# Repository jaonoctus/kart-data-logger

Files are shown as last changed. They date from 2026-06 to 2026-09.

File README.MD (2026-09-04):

# ESP32 Kart Telemetry System

A telemetry and datalogging system for open-track go-karts, built around a single
steering-wheel-mounted ESP32 display board that handles everything: GPS
acquisition, lap timing, dashboard rendering and SD logging.

> **Note:** earlier revisions of this project split the work between a
> helmet-mounted logger node and the display, linked over ESP-NOW. That helmet
> node proved unreliable at the track and has been removed — the display is now
> the only node.

## System Architecture

Single target: the **Display Dashboard Node**.

* **Board:** JC3248W535N (ESP32-S3, AXS15231B QSPI panel)
* **Role:** GPS acquisition, lap detection, UI dashboard, and SD logging.
* **Features:**
  * GPS from ATGM336 (default) or u-blox M9, wired directly to the board.
  * Live speed, G-force, satellite count and display battery state.
  * Finish-line based lap detection with best/previous lap deltas.
  * Telemetry logged to SD card per recording session.
  * Optional MPU6050 IMU for speed filtering and steering angle.

### Build targets in `platformio.ini`

Both targets build the same application (`src/main_display.cpp`) and differ only
in the panel driver backend:

* `env:display_gfx` — Arduino_GFX backend (`lib/DisplayGFX`). **Default.**
* `env:display` — esp_lcd backend (`lib/DisplayBSP`). Fallback.

The Arduino_GFX backend is the default because it resolves a QSPI panel wedge
seen with the esp_lcd path.

## Key Technical Features

* **Modular GPS provider** abstraction in `GpsManager`.
* **Finish-line lap detection** in `LapManager`, driven by GPS position.
* **`fix_stride.py` prebuild patch** for SquareLine Studio LVGL 9 image exports.
* **Display-wedge watchdog** — a 5s task watchdog on `loopTask` turns a panel
  wedge into a fast auto-reset instead of a permanent freeze.
* **Charge mode** to keep the board from eating the charger's current budget.
* **Optional IMU support** to improve speed filtering and live telemetry.

## Charge mode

The charger's current is shared between the board and the cell, so a running
dashboard slows charging considerably. Charge mode parks the device:

* Stops the recording session and closes the GPS UART.
* Drops the CPU to 80 MHz (the floor for stable USB-CDC — don't go lower).
* Swaps to a minimal charge screen and blanks the backlight after 15s.

It is **only ever entered manually**, from the `CHARGE MODE` button on the
config screen. Nothing enters it automatically, so bench testing and debugging
are unaffected.

While parked: tap anywhere to wake the backlight and read the battery for
another 15s; press `RESUME` to leave. Resuming re-probes the GPS, which takes a
couple of seconds.

> **Whether the GPS actually sleeps depends on which one is fitted.** Charge mode
> calls `gps.standby()` and leaves the UART open so `wake()` can talk to it.
> On the **ATGM336** that is a quiesce, not a sleep: the RF front end has no
> software power-down at all, so it keeps drawing ~25-40 mA and standby only cuts
> it to GPS-only at 1Hz with NMEA muted. On the **u-blox M9** it is a real
> power-down — `UBX-RXM-PMREQ` software backup, woken by traffic on the module's
> RX pin. Coming back may cost a cold start if the module's V_BCKP does not hold
> the BBR, but the configuration itself is in flash and survives either way.

> **The percentage reads high while charging.** With no power-path charger the
> sense divider sits on the charger rail, so it measures the cell terminal
> voltage *under charge*, which is well above its resting value — expect a
> jump downward when you unplug. It's shown as `~94%` to mark it approximate;
> the voltage below it is the number to trust.

The charge screen and the config-screen button are both built at runtime in
`lib/UiHelper/uiHelper.cpp` rather than exported from SquareLine, so
re-exporting `lib/ui/` will not wipe them.

## Hardware Requirements

* JC3248W535N display board
* GPS module wired to `RX=6` / `TX=7` — ATGM336, or a u-blox M9 such as the Matek
  M9N-5883. The ATGM336 runs on 3V3; the M9N-5883 wants 4~5.5V, so its VCC belongs
  on the IP5306 5V rail, not the board's 3V3.
* Optional MPU6050 IMU
* microSD card formatted FAT32

## Software Dependencies

Built with PlatformIO.

* `lvgl/lvgl` (v9.x)
* `moononournation/GFX Library for Arduino` (`display_gfx` only)
* `mikalhart/TinyGPSPlus`
* `ElectronicCats/MPU6050`

## GPS Providers

`GpsManager` supports two providers. Nothing older than these is supported — the
NEO-6M-era 9600-baud fallback is gone.

* **ATGM336 provider** (current default)
  * Enabled with `-D GPS_PROVIDER_ATGM336`.
  * 10Hz.
  * Configured over CASIC text commands (`$PCAS`), which are never acked, so the
    module cannot report whether a setting took. It also cannot be put to sleep:
    `$PCAS12` standby is a 5L-only feature and this is a 5N.
* **u-blox M9 provider** — targets the M9 generation (NEO-M9N), e.g. the Matek
  M9N-5883.
  * Leave `-D GPS_PROVIDER_ATGM336` out of the build flags.
  * 25Hz.
  * Probes 115200 then 38400 (the M9 default), and moves the port to 115200.
  * Sleeps for real in charge mode — `UBX-RXM-PMREQ` software backup, armed to
    wake on UART RX traffic.
  * Configured over binary UBX, which *is* acked, and the provider reads the
    dynamic model / rate / power mode back at boot and logs `BEFORE:` and
    `AFTER:` lines. Legacy `UBX-CFG-*` messages are deprecated on generation 9
    but still supported; they are removed on generation 10, so a future module
    means porting `configureUblox()` to `UBX-CFG-VALSET`.
  * **Speaks `UBX-NAV-PVT`, not NMEA.** All NMEA output is disabled. One 92-byte
    frame per epoch carries position at 1e-7° (~1.1cm), Doppler ground speed,
    UTC, `numSV`, `fixType`, `pDOP`, `hAcc` and `sAcc` — less traffic than
    GGA+RMC and strictly more information, as one coherent snapshot instead of a
    position from one sentence stitched to a speed from another. It also makes the
    four-constellation problem vanish: per-system duplication of GSA/GSV was an
    NMEA artefact, and UBX has no talker IDs to multiply.
  * `hasFix()` therefore uses the receiver's own verdict — `gnssFixOK`,
    `fixType == 3`, and `hAcc` within bounds — rather than the `sats >= 4 &&
    HDOP <= 3` heuristic the NMEA path had to guess with.
  * **TinyGPSPlus is unused on this path.** It stays in `lib_deps` for the
    ATGM336, and static-archive linking drops it (and the unreferenced provider)
    from the image. It is still compiled every build, so a break in either
    provider still fails the build.

The flag lives in `[display_common] -> build_flags_base`, so it applies to both
build targets at once.

### Fix rate

ATGM336 runs at **10Hz**, u-blox M9 at **25Hz** — the receiver's ceiling with all
four constellations. GGA+RMC at 25Hz is ~36kbaud of the 115200 the port is set to,
so the link has room to spare. 40ms epochs also land on exact centisecond values
(`.00`/`.04`/`.08`…), which matters because NMEA timestamps are centiseconds and
anything finer would round.

The rate buys **log resolution**, which is the point — at 100 km/h, 25Hz puts a
sample every 1.1m instead of every 2.8m. It buys much less for lap times, because
`LapManager` intersects the finish gate with the segment between consecutive fixes
and interpolates the crossing millisecond along it, so the reported time never
quantised to the fix interval in the first place.

To sustain 25Hz, `LogManager` holds the log file open for the whole session and
`flush()`es once a second, rather than reopening and closing it per row (25 FAT
directory updates a second is where a slow card starts stalling). The trade is
durability: an abrupt power-off now costs up to a second of the lap instead of a
single sample. The telemetry queue is 40 frames for the same reason — ~1.6s of
headroom at 25Hz, so a card stall doesn't drop rows.

### GPS wiring

The GPS UART pins are set by `GPS_STANDALONE_RX` / `GPS_STANDALONE_TX` in
`[display_common]`, currently `6` and `7`.

Watch for collisions when changing these: `GPIO5` carries the battery sense
divider (`DISPLAY_BATT_ADC` in `src/main_display.cpp`), and `GPIO18`/`GPIO17`
are the IMU's I2C pins when `ENABLE_IMU` is set.

## Filesystem & Storage

The display reads and writes to a **FAT32 microSD** card. No files need to be
pre-populated — the display creates what it needs on first boot — but the files
below may be edited on a computer for configuration.

#### `/config.ini` (auto-created)

Stores display preferences. Created with defaults on first boot if absent.

```ini
# Kart Data Logger Configuration
theme=dark          # dark | light
selected_track=0    # index into tracks.ini
```

#### `/health.csv` (auto-created, only when something goes wrong)

Appended across every session, one row per second in which the telemetry queue
had no room for a frame:

```
epoch,log,dropped_total,dropped_delta
```

**An empty or absent file is the good news** — it means no row was ever lost. Any
row in it means the card could not keep up with the fix rate and the matching
`log_N.csv` is missing samples, so the file is worth checking after a race rather
than watching the serial log, which is unreachable with the dash on a wheel.

`epoch` comes from the GPS-synced system clock, so it lines up with the `epoch`
column in the telemetry file; before the first fix it degrades to uptime.

#### `/tracks.ini` (optional, user-created)

Defines named tracks with GPS finish-line coordinates. The display reads this at
boot and populates the track selector in the UI. If absent, no tracks are
preloaded.

```ini
# Kart track configurations
count=2

0_name=Kartódromo Granja Viana
0_left_lat=-23.60488969
0_left_lon=-46.83622658
0_right_lat=-23.60493793
0_right_lon=-46.83641597

1_name=My Track
1_left_lat=0.00000000
1_left_lon=0.00000000
1_right_lat=0.00000000
1_right_lon=0.00000000
```

#### `/log_N.csv` (auto-created per session)

Telemetry session logs. A new numbered file is created each time a recording
session starts.

```
epoch,speed,totalGForce,gForceX,gForceY,steering_angle,sats,lat,lng,fix,pdop,hacc,sacc
```

The last four are the receiver's report on its own fix, and are **zero on the
ATGM336** — NMEA carries no equivalent, so zero means "not reported", not "perfect".

| column | meaning |
| --- | --- |
| `fix`  | `0` no fix, `2` 2D, `3` 3D, `5` time only. Never `1`/`4` (dead reckoning) — that is NEO-M9V silicon, not M9N. |
| `pdop` | position dilution of precision |
| `hacc` | horizontal accuracy estimate, metres, ~1σ |
| `sacc` | speed accuracy estimate, m/s |

`hacc` is the useful one for analysis: it does not make a position better, it tells
you which samples to distrust. Around 0.7-1.5m under open sky, climbing near
buildings and in the first seconds after a cold start. A lap time interpolated
between two 12m samples is not a lap time to trust to hundredths.

These columns are **appended**, never inserted, so everything in `tools/` keeps
working — those read by column name or by a fixed `sscanf` prefix. A CSV derived
from GoPro footage simply lacks them.

Note `lat`/`lng` are written at 7 decimal places (~1.1cm) rather than 6 (~11cm),
which is what `UBX-NAV-PVT` actually resolves.

## Setup & Installation

1. Clone this repository.
2. Open it in VSCode with PlatformIO.
3. Edit the UI using the SquareLine Studio project files in `UIDesign/`.
4. Export the UI to `/lib/ui/` and let `fix_stride.py` patch LVGL image metadata during build.
5. Flash the firmware: `tools/flash.sh` (see below).
6. Insert a FAT32 microSD card into the display. A default `config.ini` is created on first boot.

### Flashing

`upload_port` in `platformio.ini` is pinned to `/dev/cu.usbmodem1101`, which is one
machine's enumeration — the same board comes up under a different name elsewhere and
`pio run -t upload` then fails on a port that isn't there. `tools/flash.sh` finds the
board by USB `VID:PID` instead and passes it with `--upload-port`, which overrides the
pinned value:

```bash
tools/flash.sh              # default env, confirm, then upload
tools/flash.sh -m           # ...and open the serial monitor afterwards
tools/flash.sh -e display   # the esp_lcd fallback env
tools/flash.sh -p /dev/cu.usbmodem101   # skip discovery
tools/flash.sh -y           # no confirmation prompt (also FLASH_YES=1)
tools/flash.sh -- -v        # anything after -- goes to `pio run`
```

Before uploading it prints the port, env and `FW_VERSION`, and warns if the tree is
dirty — `FW_VERSION` is `git describe --tags --always --dirty` and shows on the setup
screen, so it is easy to flash uncommitted edits by accident. If more than one board is
attached it lists the candidates and asks for `-p`.

`pio run -e display_gfx -t upload` still works if the pinned port happens to be right.

## Dormant libraries

These libraries are no longer part of the build — nothing includes them — but
they are kept in `lib/` because they may be useful again:

* `EspNowManager` + `Shared/EspNowProtocol.h` message types — the board-to-board radio link.
* `ErrorLogManager` — LittleFS error capture and transfer.
* `AudioManager`, `VoiceParser` — I2S playback and spoken number/lap announcements.
* `PowerManager` — button-driven hibernate and power gating.
* `FakeGps` — CSV replay for development without GPS hardware.

`Shared/EspNowProtocol.h` is still compiled: `TelemetryMsg` is the record the
display passes between the UI, the lap manager and the SD log task.

## Design files

Design files are included under the `hardware/` folder.

### 3D Models

I've used Fusion to design 3D models for the custom enclosures and mounts. These
are located in `hardware/3d-models/` and exported as `.f3d` and `.3mf` files.
You can open and modify these in Fusion or any compatible 3D modeling software.

## Visual Reference

The repository includes module photos in the `images/` folder.

Wheel module assembled

## Notes

* The display firmware owns the whole pipeline: GPS, lap timing, UI and SD logging.
* Lap detection only runs while a recording session is active.

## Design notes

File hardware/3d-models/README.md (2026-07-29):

# 3D Models

This folder contains the Fusion 360 source models and assembly exports used to validate the kart display enclosure and its subcomponents.

## Included files

* `Display.f3d` — main display enclosure model.
* `Display Assembly.3mf` — assembly export showing how the display, rear cover, battery support, and wheel holder fit together.
* `Battery.f3d` — battery pack model and holder details.
* `4056 Battery Charger.f3d` — USB-C charging board model and placement.
* `GPS.f3d` — GPS enclosure model.
* `MP6050.f3d` — IMU module model.

## Design intent

The primary part is `Display.f3d`. The other models were created to build the assembly and verify that all pieces fit correctly.

## Mounting and fastening

* The display board is held in place by small pegs that fit into matching bosses in the enclosure.
* The back cover is pressed onto the display body by rear cover pegs and then bolted in place.
* The back cover uses eight `M3X3X5` heat inserts and eight `M3x6` bolts.
* The GPS enclosure uses four `M2.5x6mm` bolts and four `M2.5x4x4mm` heat inserts.
* The GPS holder fits the ATGM336 module and a `25x25mm` antenna.

## Battery and charging

* The rear cover supports a `LGBH4ZB4857` 2000mAh battery.
* The battery is sourced from a Dell Latitude 5490 battery pack, which contains three of these cells.
* A `4056` 1A USB-C charging board is integrated into the back cover space.

## Wheel holder and battery cover

* The battery cover / wheel holder assembly is not permanently fixed to the back cover.
* It is held in place by velcro loops that attach from the front of the display case, securing the assembly without rigid fasteners.
* The wheel holder is fixed to the rear plate using four `M3X3X5` heat inserts and four `M3x6` bolts.
* This wheel holder section can be modified for different kart wheel sizes, or multiple sizes can be printed and swapped without redesigning the entire case.

## IMU placement

* The IMU is mounted to the front of the battery back plate using double-sided tape.

## Notes

* Use the Fusion 360 `.f3d` files for source edits and design updates.
* The `.3mf` assembly file is useful for fit verification and export to compatible printing workflows.
* Confirm fastener lengths and insert positions before printing if you modify the enclosure geometry.

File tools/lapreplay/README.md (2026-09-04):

# Lap replay harness

Offline test rig for finish-line detection. Turns a GoPro's telemetry into the
logger's own CSV format and replays it through the **real** `lib/LapManager`
compiled for the host — so lap detection can be validated without going to the
track.

Nothing here is part of the firmware build. `tools/` is outside `build_src_filter`
and `lib/`, so PlatformIO never sees it.

`make` also builds **`navpvt`**, an offset-level check on the real
`UbloxGpsProvider::update()` — it feeds synthetic `UBX-NAV-PVT` frames through a
byte-queue serial stub and asserts what the provider decodes. Run it after touching
that provider: it decodes by explicit byte offset, and a wrong offset does not crash,
it produces plausible telemetry that is silently wrong. It covers the field offsets,
the `hasFix()` gates (2D rejected, `hAcc` bound), checksum rejection, mm/s→km/h
scaling, and a frame split at every byte boundary — that last one being the real 25Hz
failure mode, where a message straddles two `update()` calls because the UART buffer
drained mid-frame.

## Why a GoPro

GoPro MP4s carry a GPMF metadata track alongside the video. On a HERO8 that is
GPS at ~18 Hz and accelerometer/gyro at ~200 Hz — denser than the ATGM336's
10 Hz, already timestamped in UTC, and free if you were filming anyway.

## Usage

```sh
# 1. extract telemetry -> CSV (no ffmpeg/exiftool needed; parses the MP4 directly)
python3 gpmf_to_csv.py ../../video/GH011973.MP4 GH011973.csv

# 2. build the harness
make

# 3. replay against a finish line: <csv> <leftLat> <leftLng> <rightLat> <rightLng>
./replay GH011973.csv -23.60488969 -46.83622658 -23.60493793 -46.83641597
```

`make VERBOSE=1` surfaces `LapManager`'s own `log_d()` gate diagnostics
("Approaching Gate", "Gate Missed!", "VALID CROSSING") which are compiled out by
default.

### Testing lap *timing*

A single crossing only starts the clock — it produces no lap time. If the clip is
a near-closed loop, stitch it into synthetic laps:

```sh
python3 gpmf_to_csv.py ../../video/GH011973.MP4 looped.csv --repeat 4
./replay looped.csv -23.60488969 -46.83622658 -23.60493793 -46.83641597
```

Each reported lap should equal the printed span exactly; any drift is a bug in
the crossing interpolation.

## Column mapping

Output matches `LogManager::task`'s `/log_N.csv` exactly:

```
epoch,speed,totalGForce,gForceX,gForceY,steering_angle,sats,lat,lng
```

| column | source | notes |
|---|---|---|
| `epoch` | `GPSU` | absolute UTC, 1 Hz; the 18 Hz `GPS5` samples are interpolated between stamps |
| `speed` | `GPS5` 2D speed | m/s → km/h |
| `totalGForce` | `ACCL` magnitude | orientation-independent, always correct |
| `gForceX/Y` | `ACCL` axes | **see caveat below** |
| `steering_angle` | — | always `0.0`; a camera cannot know this |
| `sats` | `GPSF` | GPMF has no satellite count, only fix type and DOP. Emitted as `12` on a 3D fix, else `0`, because `LogManager` and `LapManager` treat `sats == 0` as unusable |
| `lat`/`lng` | `GPS5` | 6 dp, ~0.11 m resolution |

**Axis caveat:** GPMF's accelerometer axis order depends on camera mount
orientation (see the `ORIN`/`ORIO` tags). The X/Y assignment is a starting guess —
verify against a known corner before trusting `gForceX`/`gForceY`. Raw accel also
peaks around 6 g from chassis vibration, so samples are averaged into each GPS
interval to damp it.

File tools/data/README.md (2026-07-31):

# Recorded GPS tracks

Raw GPS as it came off the GoPro's GPMF track, one file per chapter of a single
12-lap session (Kartódromo Granja Viana, 2026-07-23). Committed because the
source footage is ~1.2 GB and lives outside the repo: with these, lap detection
can be exercised on real track data without it.

| file | samples | span | notes |
|---|---|---|---|
| `gps_raw_GH011974.csv` | 9,548 | 532.8 s | starts before the race; 2 corrupt near-(0,0) samples left in |
| `gps_raw_GH021974.csv` | 7,508 | 423.2 s | continues the same recording past the 4 GB split |

Both are ~18 Hz, 3D fix throughout, DOP 1.1–1.9. Columns and their exact
provenance are documented at the top of `../lapreplay/gpmf_gps_raw.py`; nothing
is filtered or converted, including the corrupt samples.

## Replaying them

`gps_raw_to_log.py` merges the chapters back into one session in the logger's
own CSV format, which `replay` feeds through the firmware's real `LapManager`:

```sh
cd ../lapreplay && make
python3 gps_raw_to_log.py --out /tmp/session.csv ../data/gps_raw_GH0*1974.csv
./replay /tmp/session.csv -23.605392 -46.836045 -23.605442 -46.836251
```

That yields 12 crossings, best lap 1:02.628 — identical to what the full
video-derived pipeline (`tools/overlay/prepare.py`) produces, so this is a
faithful stand-in for it and a usable regression fixture.

## What is *not* here

No video timeline. GPMF telemetry does not sit at a fixed offset from the
picture — the overlay needed ~1.2 s of correction on chapter 1 and closer to
2 s on chapter 2 — so the two cannot be related without re-measuring per clip.
The GPS timeline against itself is sound, which is the part that matters for
lap logic.

No accelerometer. The g-force channels need axis calibration against gyro and
speed, which `gpmf_to_csv.py` does from the video.

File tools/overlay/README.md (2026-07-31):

# Telemetry overlay

Renders a dashboard-style overlay onto GoPro race footage: track map, g-force
wheel, speed, race/lap time and lap number. Telemetry comes from the videos' own
GPMF track, so nothing has to be recorded on the device.

Lap numbers come from the firmware's **real** `LapManager`, via
`tools/lapreplay/replay --csv`. The overlay and the kart dashboard therefore
agree by construction rather than by a reimplementation that can drift.

## Requirements

* `ffmpeg` on PATH — `brew install ffmpeg`
* Pillow — already installed in `.venv/` here (`python3 -m venv .venv && .venv/bin/pip install Pillow`)
* `tools/lapreplay/replay` built — `cd ../lapreplay && make`

## Usage

```sh
# 1. order the clips, merge telemetry, trim to race start, detect laps
python3 prepare.py \
    --videos ../../video/*.MP4 \
    --race-start GH011974.MP4:186 \
    --finish-line -23.60488969 -46.83622658 -23.60493793 -46.83641597 \
    --outdir build

# 2. render (start/duration are seconds after the race start)
.venv/bin/python render.py --config build/session.json \
    --start 210 --duration 3 -o test.mp4
```

`--frames-only DIR` writes PNG frames instead of encoding, which needs no
ffmpeg and is the quick way to check layout changes.

Output defaults to 1080p. The source is 4K, so ffmpeg downscales it — 4K output
is enormous and very slow to encode for no real benefit when watching.

## Telemetry lag

GPMF telemetry runs behind the picture: the overlay reacts about a second after
the corner is already on screen. `--lag` advances the telemetry against the
video and defaults to **1.2 s**, chosen by rendering the same braking-and-corner
section at 1.2 / 1.4 / 1.5 / 2.0 / 2.5 and watching which one lands.

GPS and accelerometer lag together — cross-correlating `ACCL` against the
GPS-derived lateral acceleration puts them within 0.17 s of each other — so
`--lag` moves both. `--lag-g` can shift only the g-wheel if you ever want them
apart; it defaults to whatever `--lag` is.

```sh
.venv/bin/python render.py --config build/session.json \
    --start 210 --duration 12 --lag 1.4 -o lagtest_1.4.mp4
```

## Clip ordering

`prepare.py` orders clips by the UTC in their GPMF track, **not** by filename.
This matters: GoPro splits a single recording at the 4 GB FAT32 limit into
`GH01xxxx`, `GH02xxxx`, … so chapter 2 of one recording sorts before chapter 1
of the next, and unrelated recordings can interleave.

Clips separated by more than `--max-gap` seconds (default 5) from the previous
one are treated as a different session and dropped, with a note. For this
footage that correctly kept `GH011974` + `GH021974` (consecutive chapters,
seamless) and dropped `GH011975`/`GH011976`, which were recorded 14 hours later.

## Accelerometer axes

GPMF's accelerometer axis order depends on how the camera was mounted, so
`gpmf_to_csv.calibrate_axes()` derives it from the data:

* **vertical** — the axis carrying gravity (largest absolute mean)
* **lateral** — the horizontal axis correlating with `v × yaw_rate`, because
  cornering acceleration is exactly that
* **longitudinal** — whichever horizontal axis remains

Yaw is rotation about the vertical axis, so the gyro axis used is the same index
as the gravity axis; if those disagree the calibration is suspect. On this
footage both chapters independently resolved to `vertical=0, lateral=1,
longitudinal=2` with r ≈ +0.55.

Each axis's mean is subtracted, which removes gravity and any camera tilt
leaking into the horizontal axes. `totalGForce` is therefore the **horizontal**
magnitude — including gravity would make it read ~1 g at a standstill and would
not match the position of the dot on the wheel.

Residual peaks around 3–4 g are kart chassis vibration, not real cornering load;
the accelerometer samples inside each GPS interval are averaged to damp it.

## Layout

| element | position | source |
|---|---|---|
| lap number, current lap, last, best | top left | `laps.csv` from `LapManager` |
| race clock | top right | elapsed since race start |
| speed | bottom centre | `GPS5` 2D speed |
| g-force wheel, 1 g / 2 g rings | bottom right | calibrated `ACCL` |
| track map, finish line, position | bottom left | `GPS5` lat/lng |

Colours are the dashboard's `THEME_NIGHT` palette from `lib/UiHelper/uiHelper.h`.

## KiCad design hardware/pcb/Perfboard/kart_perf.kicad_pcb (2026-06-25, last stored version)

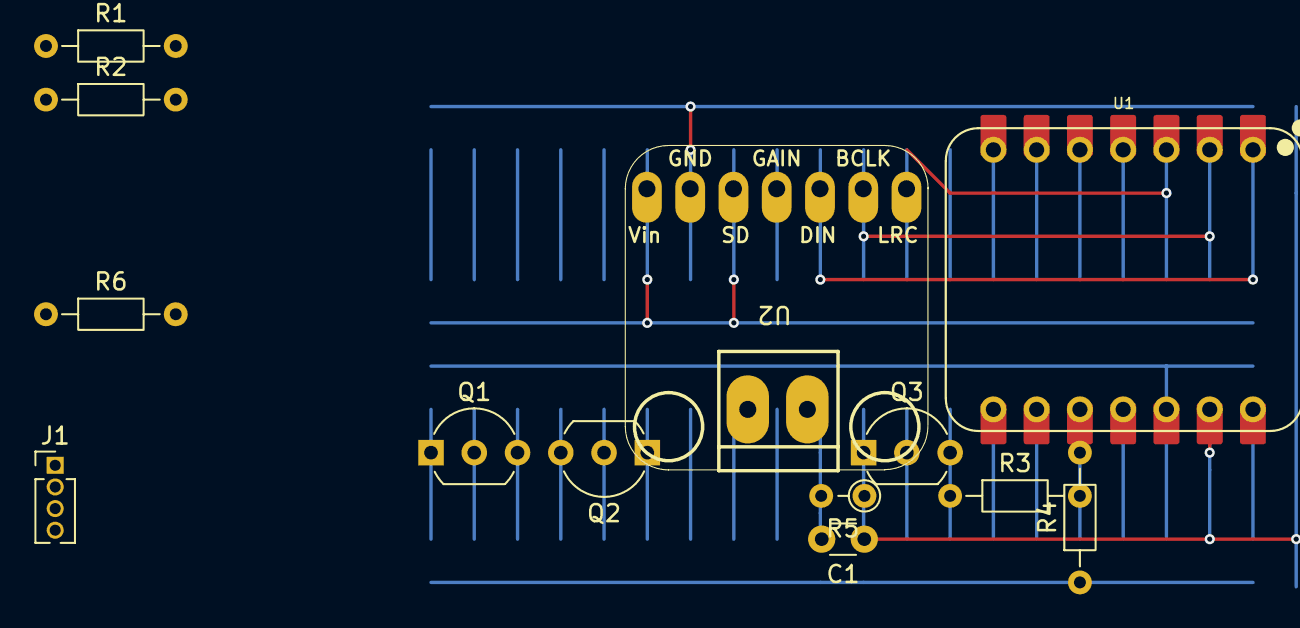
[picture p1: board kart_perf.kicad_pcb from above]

Board: 2 copper layers, 13 parts (0 on the bottom side), 16 nets.

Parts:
C1: 0.1uf; C_Disc_D3.0mm_W1.6mm_P2.50mm
J1: Conn_01x04_Pin; PinHeader_1x04_P1.27mm_Vertical
Q1: BC327; TO-92_Inline_Wide
Q2, Q3: 2N3904; TO-92_Inline_Wide
R1, R3, R6: 10k; R_Axial_DIN0204_L3.6mm_D1.6mm_P7.62mm_Horizontal
R2: 470; R_Axial_DIN0204_L3.6mm_D1.6mm_P7.62mm_Horizontal
R4: 1M; R_Axial_DIN0204_L3.6mm_D1.6mm_P7.62mm_Horizontal
R5: 1M; R_Axial_DIN0204_L3.6mm_D1.6mm_P2.54mm_Vertical
U1: XIAO-ESP32-S3-SMD; XIAO-ESP32-S3-DIP
U2: adafruit-MAX98357

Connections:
+3.3V: Q1.3 (E), R1.2, U1.12 (3V3)
/BATT_EN: R6.2, U1.11 (GPIO9_A10_D10_MOSI)
/PERIF_EN: R3.1, U1.4 (GPIO4_A3_D3)
/SENSE: C1.2, R4.2, R5.2, U1.10 (GPIO8_A9_D9_MISO)
/V_PERIF: J1.3, Q1.1 (C), U2.1 (Vin), U2.3 (~SD_MODE)
GND: J1.4, Q2.1 (E), Q3.1 (E), U1.13 (GND), U2.2 (GND)
unnamed: J1.1, U1.7 (GPIO43_D6_TX)
unnamed: J1.2, U1.8 (GPIO44_D7_RX)
unnamed: Q1.2 (B), R1.1, R2.1
unnamed: Q2.2 (B), R3.2
unnamed: Q2.3 (C), R2.2
unnamed: Q3.2 (B), R6.1
unnamed: C1.1, Q3.3 (C), R5.1
unnamed: U1.1 (GPIO1_A0_D0), U2.5 (DIN)
unnamed: U1.2 (GPIO2_A1_D1), U2.6 (BCLK)
unnamed: U1.3 (GPIO3_A2_D2), U2.7 (LRC)

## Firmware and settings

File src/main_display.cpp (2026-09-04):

#include <Arduino.h>
#include "esp_task_wdt.h"   // display-wedge safety net (used throughout)
#include "esp_system.h"     // esp_reset_reason

// QSPI flush telemetry from lib/DisplayBSP/lv_port.c (C linkage). Reported once a
// second below via log_w so it surfaces at CORE_DEBUG_LEVEL=WARN.
extern "C" {
    extern volatile uint32_t lvgl_port_frame_drops;
    extern volatile uint32_t lvgl_port_max_stall_us;
}

// Library includes from our new /lib folder
#include "LogManager.h"
#include "EspNowProtocol.h"
#include "uiHelper.h"
#include "BatteryManager.h"
#include "ConfigManager.h"
#include "LapManager.h"
#include "GpsManager.h"

#if defined(ENABLE_GOPRO)
#include "GoProManager.h"
#endif

#if defined(ENABLE_WEB_PORTAL)
#include "WebPortal.h"
#endif

#include "SessionBrowser.h"
#include "LogBuffer.h"
#include "LogScreen.h"

// Opens the on-device session review screens. Called from the config screen,
// already in LVGL context — the browser loads a placeholder and repaints before
// the (slow) SD read, so the press feels immediate.
extern "C" void ui_helper_open_sessions(void) {
    sessionBrowser.openList();
}

// Opens the log screen. Reached from the config screen and from the dashboard
// alert banner. Renders out of LogBuffer's RAM ring, so unlike the session
// browser there is no slow read to defer — it can run in LVGL context.
extern "C" void ui_helper_open_logs(void) {
    logScreen.open();
}

#if defined(ENABLE_IMU)
#include "ImuManager.h"
#include "CalibrationManager.h"

#define I2C_SDA 18
#define I2C_SCL 17
#endif

const uint8_t timeBetweenImuReads = 10; // ms between IMU reads (100 Hz)

// --- GLOBAL STATE ---
LogManager logManager;
UiHelper   uiHelper;
LapManager lapManager;

GpsManager gps(GPS_STANDALONE_RX, GPS_STANDALONE_TX);

#if defined(ENABLE_GOPRO)
GoProManager goPro;
#define GOPRO_UI_INTERVAL_MS 500
static uint32_t lastGoProUiMs = 0;
#endif

#if defined(ENABLE_WEB_PORTAL)
WebPortal webPortal;
#define WEB_PORTAL_UI_INTERVAL_MS 1000
static uint32_t lastWebUiMs = 0;

// Called from the config-screen button (LVGL context). start() brings up the
// SoftAP and HTTP server, which takes a moment — acceptable here because the
// user just pressed a button and the portal task does the serving.
extern "C" void ui_helper_toggle_wifi(void) {
    if (webPortal.isRunning()) {
        webPortal.stop();
#if defined(ENABLE_GOPRO)
        goPro.resumeRadio();
#endif
        uiHelper.setWifi(false, 0, nullptr);
        return;
    }

    // WiFi needs ~50 kB of internal DRAM and cannot use PSRAM; NimBLE is
    // holding a comparable amount, so the BLE stack stands down first.
    // Otherwise esp_wifi_init fails with ESP_ERR_NO_MEM.
#if defined(ENABLE_GOPRO)
    goPro.suspendRadio();
#endif
    bool up = webPortal.start();
    if (!up) {
#if defined(ENABLE_GOPRO)
        goPro.resumeRadio();      // give it back, we did not need it after all
#endif
        uiHelper.setWifiError();  // say so on the button rather than sit silent
        return;
    }
    String wip = webPortal.ip();
    uiHelper.setWifi(true, webPortal.clients(), wip.c_str());
}
#else
extern "C" void ui_helper_toggle_wifi(void) {}
#endif

// Latest assembled telemetry frame. Written by loop() from the local GPS (plus
// IMU when enabled), consumed by syncUI() for the dashboard and the SD log.
static TelemetryMsg telemetry = {};
static bool newTelemetryAvailable = false;

#if defined(ENABLE_IMU)
ImuManager imu;
CalibrationManager calibManager(imu);
ImuData latestImuData = {0};
bool imuReady = false;
uint32_t lastImuReadMs = 0;
#endif

// Display battery: BAT+ → 68k (683) → IO5 → 100k (01D) → GND (always-on divider)
// Theoretical ratio is 1.68; the ADC reads low (~40k source impedance starves its
// sample-and-hold), so it is fitted to a multimeter instead. To re-fit: scale by
// meter/reported, on battery only — with USB in the node is the charger rail.
// ponytail: gain-only fit, exact at ~4.0V. If it reads high near 3.5V, take a point
// down there and go two-point (gain + offset).
#define DISPLAY_BATT_ADC 5
#define DISPLAY_BATT_READ_INTERVAL_MS 5000
BatteryManager displayBattery(DISPLAY_BATT_ADC, 0xFF, 1.7269f);
static uint32_t lastDisplayBattReadMs = 0;

// Smoothing & Metrics
float displaySpeed = 0;
float targetSpeed = 0;
const float lerpFactor = 0.20f;
static uint32_t lastHealthReportMs = 0;

// Lap state — updated inside syncUI()
static uint8_t s_lapCount = 0;

// Push a track's split gates into LapManager. Must follow setFinishLine(),
// which clears them — the splits belong to a track, so a new finish line
// invalidates them.
static void applySectorGates(const TrackConfig *t) {
    if (!t) return;
    FinishLine s1 = { t->s1.left_lat, t->s1.left_lon, t->s1.right_lat, t->s1.right_lon };
    FinishLine s2 = { t->s2.left_lat, t->s2.left_lon, t->s2.right_lat, t->s2.right_lon };
    lapManager.setSectorGates(t->s1.usable() ? &s1 : nullptr,
                              t->s2.usable() ? &s2 : nullptr);
}

// ============================================================================
// CHARGE MODE
// Entered only from the CHARGE MODE button on the config screen — never
// automatically — so debugging and bench testing are unaffected.
// Parks the device so the charger's current budget goes to the cell instead of
// the load: GPS off, session stopped, CPU down, backlight on a timeout.
// ============================================================================
#define CHARGE_CPU_MHZ              80     // USB-CDC needs >= 80MHz; do not go lower
#define NORMAL_CPU_MHZ              240
#define CHARGE_BACKLIGHT_TIMEOUT_MS 15000  // both on entry and after a tap
#define CHARGE_BATT_INTERVAL_MS     5000
#define CHARGE_LOOP_DELAY_MS        50

static bool s_chargeMode         = false;
static bool s_chargeBacklightOn  = false;
static uint32_t s_chargeBacklightOnMs = 0;
static uint32_t s_chargeBattReadMs    = 0;

// Set from LVGL event callbacks, consumed in loop(). The callbacks must stay
// trivial: entering/leaving charge mode blocks for seconds, which would wedge
// the LVGL task while it holds the display lock.
static volatile bool s_chargeEnterPending = false;
static volatile bool s_chargeExitPending  = false;
static volatile bool s_chargeTouchPending = false;

extern "C" void ui_helper_enter_charge_mode(void) { s_chargeEnterPending = true; }
extern "C" void ui_helper_exit_charge_mode(void)  { s_chargeExitPending  = true; }
extern "C" void ui_helper_charge_screen_touched(void) { s_chargeTouchPending = true; }

// ============================================================================
// DISPLAY-WEDGE SAFETY NET (ALWAYS ON) - "indestructible" recovery.
// The AXS15231B QSPI panel write (panel_axs15231b_draw_bitmap) can occasionally
// hang the LVGL task while it holds the display lock, which would otherwise
// freeze the whole UI forever (screen + touch + serial dead). The spin cannot
// be safely unstuck in place, so we guarantee recovery instead: a short Task
// Watchdog on loopTask converts a wedge into a fast auto-reset (~5s) and the
// dash comes straight back.
// Timeout keeps headroom over legitimate slow paths (SD writes) so it only ever
// fires on a genuine *infinite* wedge, never on a transient stall.
// ============================================================================
#define DISPLAY_WDT_TIMEOUT_MS 5000

// Recovery counter persisted across the panic-reset (RTC memory survives a SW
// reset; it is garbage on a true power-on, so guard it with a magic value).
RTC_NOINIT_ATTR static uint32_t s_recoveryMagic;
RTC_NOINIT_ATTR static uint32_t s_recoveryCount;

static void displayWdtInit() {
    esp_task_wdt_config_t twdt = {};
    twdt.timeout_ms     = DISPLAY_WDT_TIMEOUT_MS;
    twdt.idle_core_mask = 0;
    twdt.trigger_panic  = true;   // a genuine loopTask wedge -> fast auto-reset
    if (esp_task_wdt_reconfigure(&twdt) != ESP_OK) {
        esp_task_wdt_init(&twdt);   // not yet initialized by the Arduino core
    }
    esp_task_wdt_add(NULL);          // subscribe loopTask; fed each loop()
}

static void reportRecoveryOnBoot() {
    esp_reset_reason_t rr = esp_reset_reason();
    if (s_recoveryMagic != 0xC0FFEE42u) {   // fresh power-on: RTC RAM is garbage
        s_recoveryMagic = 0xC0FFEE42u;
        s_recoveryCount = 0;
    }
    if (rr == ESP_RST_TASK_WDT || rr == ESP_RST_INT_WDT ||
        rr == ESP_RST_WDT      || rr == ESP_RST_PANIC) {
        s_recoveryCount++;
        log_w("=== AUTO-RECOVERED from display wedge (reset_reason=%d, recoveries this power cycle=%u) ===",
              (int)rr, s_recoveryCount);
    } else {
        s_recoveryCount = 0; // normal power-on / flash / external reset
    }
}

// ============================================================================
// BRIDGES (called from LVGL event callbacks via ui_theme.cpp)
// Already in LVGL task context — do NOT call bsp_display_lock here.
// ============================================================================
extern "C" void ui_helper_apply_finish_line(double ll, double ln, double rl, double rn) {
    FinishLine fl = { ll, ln, rl, rn };
    lapManager.setFinishLine(fl);
    // setFinishLine() clears the split gates by design — a new finish line
    // belongs to a different track, so stale splits would be wrong. That means
    // every caller must put them back, or saving a track silently kills sector
    // timing until the next reboot.
    applySectorGates(configManager.getTrack((int)configManager.getSelectedTrack()));
    s_lapCount = 0; // Reset lap counter when finish line changes
}

extern "C" bool ui_helper_get_gps(double *lat, double *lon) {
    if (!telemetry.hasFix) return false;
    *lat = telemetry.lat;
    *lon = telemetry.lng;
    return true;
}

extern "C" void ui_helper_toggle_session() {
    if (logManager.isSessionActive()) {
        logManager.stopSession();
        uiHelper.setSessionState(false);
#if defined(ENABLE_GOPRO)
        goPro.setRecording(false);
#endif
    } else {
        logManager.startSession();
        uiHelper.setSessionState(true);
#if defined(ENABLE_GOPRO)
        // Non-blocking: the worker connects (waking a sleeping camera) and
        // rolls the shutter as soon as the link is up.
        goPro.setRecording(true);
#endif

        // Re-apply the active track's finish line to lapManager on session start
        int sel = (int)configManager.getSelectedTrack();
        const TrackConfig *active = configManager.getTrack(sel);
        if (active && active->left_valid && active->right_valid) {
            FinishLine fl = { active->left_lat, active->left_lon,
                              active->right_lat, active->right_lon };
            lapManager.setFinishLine(fl);
            applySectorGates(active);
            s_lapCount = 0;
        }
    }
}

extern "C" void ui_helper_stop_session() {
    logManager.stopSession();
    uiHelper.setSessionState(false);
#if defined(ENABLE_GOPRO)
    goPro.setRecording(false);
#endif
}
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
void loop() {
    uint32_t now = millis();

    esp_task_wdt_reset();   // feed the display-wedge watchdog (always on)

    // Transitions run here, never in LVGL callback context.
    if (s_chargeEnterPending) {
        s_chargeEnterPending = false;
        if (!s_chargeMode) enterChargeMode();
    }
    if (s_chargeExitPending) {
        s_chargeExitPending = false;
        if (s_chargeMode) exitChargeMode();
    }

    // Ahead of everything below on purpose: charge mode is a parking state, so
    // it must not fall through to session analysis (a multi-second SD stream)
    // or the dashboard repaint. Both would defeat the point of the mode.
    if (s_chargeMode) {
        serviceChargeMode(now);
        delay(CHARGE_LOOP_DELAY_MS);
        return;
    }

    // Session analysis runs here, deliberately before the display lock is
    // taken: streaming a log takes many seconds, and doing it while holding the
    // lock would block this task and trip the watchdog.
    sessionBrowser.service();

    // Flush captured log lines to SD. Here for the same reason as the line
    // above: it touches the card, and must not run under the display lock.
    logBuffer.service();

#if defined(ENABLE_IMU)
    if (imuReady) {
        float currentSteering = calibManager.getSteeringAngle();

        if (calibManager.isDone() && (now - lastImuReadMs >= timeBetweenImuReads)) {
            latestImuData = imu.update(currentSteering);
            lastImuReadMs = now;
        }
    }
#endif

    /* Drain EVERY NAV-PVT frame, not one per pass. update() yields a single
     * frame per call now, so this loop logs all 25 per second even when a slow
     * LVGL or SD pass makes loop() itself run at 19Hz — which is exactly how a
     * measured session lost 24% of its rows without the health counter noticing,
     * the frames being discarded upstream of the queue. The UI still consumes
     * only the newest via newTelemetryAvailable; only the log needs all of them. */
    while (gps.update()) {
        /* IMU removed — no accelerometer on this build. The g-force and gyro
         * fields stay in the message (and the CSV) as zeros so old sessions and
         * SessionBrowser keep parsing; a future 9-DoF refills them. */
        telemetry.type        = MSG_TELEMETRY;
        telemetry.speedKmph   = (float)gps.getSpeed(0.0f, 0.0f);
        telemetry.gForceX     = 0.0f;
        telemetry.gForceY     = 0.0f;
        telemetry.totalGForce = 0.0f;
        telemetry.gyroZ       = 0.0f;
        telemetry.lat         = gps.getLat();
        telemetry.lng         = gps.getLng();
        telemetry.sats        = (uint8_t)gps.getSatellites();
        telemetry.hasFix      = gps.hasFix() ? 1 : 0;
        telemetry.timestamp   = gps.getEpochMs();

        // Fix quality, zeroed on providers that cannot report it (the ATGM336).
        GpsFixInfo fix        = gps.getFixInfo();
        telemetry.fixType     = fix.fixType;
        telemetry.pdop        = fix.pdop;
        telemetry.hAccM       = fix.hAccM;
        telemetry.sAccMps     = fix.sAccMps;

        /* Enqueue HERE, once per frame. This used to live in syncUI() behind the
         * newTelemetryAvailable flag, which is a one-slot handoff: whatever
         * arrived between UI passes was overwritten and never reached the queue.
         * Zero timeout still, so a full queue drops the row rather than blocking
         * the UI — but now that is a real drop the health counter can see. */
        if (LogManager::logQueue != NULL && logManager.isSessionActive()) {
            if (xQueueSend(LogManager::logQueue, &telemetry, 0) != pdTRUE) {
                logManager.noteDroppedFrame();
            }
        }

        newTelemetryAvailable = true;
    }

    // Display battery ADC read — done before the display lock to avoid blocking LVGL
    static uint8_t cachedDisplayBattPct = 255;
    static uint8_t lastDisplayBattPct = 255;
    if (now - lastDisplayBattReadMs >= DISPLAY_BATT_READ_INTERVAL_MS) {
        lastDisplayBattReadMs = now;
        cachedDisplayBattPct = (uint8_t)displayBattery.getPercentage();
        log_i("Display battery: %d%%", cachedDisplayBattPct);
    }

    /* GPS heartbeat. "GPS 0" on the dash says a fix is missing but not why, and
     * the difference matters: satellites climbing with fixType stuck at 0 is a
     * sky-view/cold-start problem and will come good if left alone; zero
     * satellites for minutes is an antenna, wiring or config problem and never
     * will. Logged unconditionally so a session that never got a fix leaves an
     * account of itself on the card. */
    static uint32_t lastGpsLogMs   = 0;
    static uint32_t lastGpsFrames  = 0;
    if (now - lastGpsLogMs >= 5000) {
        /* Measured NAV-PVT rate, not the rate we asked for. CFG-RATE is accepted
         * without complaint even when the receiver cannot sustain it, so the only
         * way to know we are really getting 25Hz is to count frames and divide. */
        uint32_t frames  = gps.getFrameCount();
        uint32_t elapsed = now - lastGpsLogMs;
        float    hz      = lastGpsLogMs && elapsed
                             ? (frames - lastGpsFrames) * 1000.0f / (float)elapsed
                             : 0.0f;
        lastGpsLogMs  = now;
        lastGpsFrames = frames;

        GpsFixInfo fi = gps.getFixInfo();
        log_i("GPS: sats=%lu fix=%u ok=%d pdop=%.1f hAcc=%.1fm rate=%.1fHz",
              (unsigned long)gps.getSatellites(), (unsigned)fi.fixType,
              fi.gnssFixOK ? 1 : 0, fi.pdop, fi.hAccM, hz);
    }

    // Once-a-second health reporting
    if (now - lastHealthReportMs >= 1000) {
        lastHealthReportMs = now;

        // QSPI flush health: report dropped frames and the worst bus-idle wait in
        // the last second, then reset the stall high-water mark. A blink should line
        // up with either a frame_drops increment (hard skip) or a high max_stall.

        /* Enqueue HERE, once per frame. This used to live in syncUI() behind the
         * newTelemetryAvailable flag, which is a one-slot handoff: whatever
         * arrived between UI passes was overwritten and never reached the queue.
         * Zero timeout still, so a full queue drops the row rather than blocking
         * the UI — but now that is a real drop the health counter can see. */
        if (LogManager::logQueue != NULL && logManager.isSessionActive()) {
            if (xQueueSend(LogManager::logQueue, &telemetry, 0) != pdTRUE) {
                logManager.noteDroppedFrame();
            }
        }

        static uint32_t lastFrameDrops = 0;
        uint32_t drops = lvgl_port_frame_drops;
        uint32_t stallUs = lvgl_port_max_stall_us;
        lvgl_port_max_stall_us = 0;
        if (drops != lastFrameDrops || stallUs >= 8000) {
            log_w("[DISP] frame_drops=%lu (+%lu)  max_bus_stall=%lu us",
                  (unsigned long)drops, (unsigned long)(drops - lastFrameDrops),
                  (unsigned long)stallUs);
            lastFrameDrops = drops;
        }

        // Log rows the queue had no room for. Also persisted to /health.csv by the
    /* GPS heartbeat. "GPS 0" on the dash says a fix is missing but not why, and
     * the difference matters: satellites climbing with fixType stuck at 0 is a
     * sky-view/cold-start problem and will come good if left alone; zero
     * satellites for minutes is an antenna, wiring or config problem and never
     * will. Logged unconditionally so a session that never got a fix leaves an
     * account of itself on the card. */
    static uint32_t lastGpsLogMs   = 0;
    static uint32_t lastGpsFrames  = 0;
    if (now - lastGpsLogMs >= 5000) {
        /* Measured NAV-PVT rate, not the rate we asked for. CFG-RATE is accepted
         * without complaint even when the receiver cannot sustain it, so the only
         * way to know we are really getting 25Hz is to count frames and divide. */
        uint32_t frames  = gps.getFrameCount();
        uint32_t elapsed = now - lastGpsLogMs;
        float    hz      = lastGpsLogMs && elapsed
                             ? (frames - lastGpsFrames) * 1000.0f / (float)elapsed
                             : 0.0f;
        lastGpsLogMs  = now;
        lastGpsFrames = frames;

        GpsFixInfo fi = gps.getFixInfo();
        log_i("GPS: sats=%lu fix=%u ok=%d pdop=%.1f hAcc=%.1fm rate=%.1fHz",
              (unsigned long)gps.getSatellites(), (unsigned)fi.fixType,
              fi.gnssFixOK ? 1 : 0, fi.pdop, fi.hAccM, hz);
    }
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

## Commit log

2026-06-24 fix(display): stop QSPI panel freeze by disabling LVGL draw thread
    The display intermittently hard-froze (screen + touch + serial dead, only a
    power cycle recovered). Root cause: the LVGL 9 upgrade. With LV_USE_OS set,
    LVGL 9 renders in a separate draw thread that overlaps the QSPI flush DMA,
    wedging the AXS15231B polling command write (an uninterruptible CPU spin while
    holding the display lock). The manufacturer's reference demo uses LVGL 8.4,
    which is single-threaded, and never wedges; our DisplayBSP is a faithful port
    of it (the panel driver is byte-identical), so LVGL 9's threading was the only
    real difference.
    Set LV_USE_OS = LV_OS_NONE so rendering and flushing run sequentially like t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
2026-06-24 feat(display): add watchdog auto-recovery for display wedges
    Defence in depth for the QSPI panel wedge: arm a 5s Task Watchdog on loopTask
    (panic+reset) so that if the panel ever hangs again, the dash auto-recovers in
    ~5s instead of freezing forever. The spin holds the display lock and a CPU and
    cannot be safely unstuck in place, so a fast reset is the guaranteed recovery.
    On boot, report whether this was a normal start or a wedge recovery, with a
    recovery counter persisted in RTC memory across the reset. The timeout keeps
    headroom over legitimate slow paths (the loopTask SD-write loop feeds the WDT)
    so it only ever fires on a genuine infinite wedge.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
    [main_display.cpp]
2026-06-24 feat(display): Arduino_GFX backend resolves the QSPI panel wedge
    The esp_lcd DisplayBSP backend wedges on the AXS15231B QSPI panel: a polling
    CASET write spins the CPU, starves the idle task, and the Task WDT reboots in
    a loop. Switching the display to an Arduino_GFX full-canvas backend eliminates
    the wedge entirely (confirmed on hardware: no resets, comparable framerate).
    - New lib/DisplayGFX: Arduino_ESP32QSPI + Arduino_AXS15231B + full-frame
    Arduino_Canvas (software 90 deg rotation, single-blit flush), I2C touch, and
    an LVGL service task. Drop-in for the bsp_display_* API, so uiHelper and
    main_display are unchanged. New env display_gfx (now default_envs); the
    esp_lcd `display` en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
    [main_display.cpp]
2026-06-25 BatteryManager: enhance button logic
2026-06-25 PowerManager: enhance button logic
2026-06-25 pcb: add perfboard circuit
    [kart_perf.kicad_pcb, kart_perf.kicad_sch, kart_smd.kicad_sch]
2026-07-10 logger: remove the IMU logic on the helmet
    also remove the need for an IMU if none is present on any module
2026-07-29 Remove the helmet logger node
    Two track sessions with different failures on the helmet unit; the
    display is now the only node. GPS is wired straight to it and it owns
    acquisition, lap timing and SD logging.
    Firmware:
    - Delete main_logger.cpp, SmokeTest.cpp and the seed_xiao partition table.
    - main_display.cpp drops EspNowManager entirely. The telemetry frame is
    now a file-scope TelemetryMsg fed from the local GPS, replacing
    EspNowManager::lastTelemetry / newDataAvailable. Gone with it: the
    error-log receiver, helmet battery, IMU uplink and lap-completed send.
    - LogManager loses the helmet error-log SD path and its ESP-NOW include.
    - Move LoggingUtils.h to lib/Shared. It lived in Error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
    [kart_perf.kicad_pcb, kart_perf.kicad_sch, kart_smd.kicad_pcb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]
2026-07-31 tools: add GPMF telemetry pipeline and recorded GPS tracks
    Host-side tooling for validating lap detection against real track data,
    plus the data itself so the 1.2 GB of footage isn't needed to run it.
    * lapreplay - compiles LapManager.cpp unmodified against an Arduino shim and
    replays a session CSV through it, so finish-line detection can be checked
    without going to the track.
    * gpmf_to_csv.py - converts a GoPro's GPMF track into the logger's own CSV
    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
    [gps_raw_GH011974.csv, gps_raw_GH021974.csv]
2026-07-31 Rotate the display 180 for the new enclosure
    The new case mounts the panel upside down. Rotation lives in two places
    because the two display backends are independent:
    - display_gfx (default): Arduino_Canvas rotation index, TFT_ROT 1 -> 3.
    gfx_touch_read_cb maps native panel coordinates into LVGL space with a
    hardcoded transform, so flipping TFT_ROT alone would leave a correctly
    rotated screen with touch inverted on both axes. The 270 mapping is the
    90 mapping with both axes flipped. Guarded with an #error so any other
    TFT_ROT fails loudly rather than silently breaking touch.
    - display (esp_lcd fallback): bsp_display_cfg_t.rotate 90 -> 270, which
    feeds both the framebuffer trans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
2026-08-03 Add GoPro BLE camera control, tied to the log session
    Starting a session wakes the camera and starts recording; stopping it
    stops recording. The dash also shows camera battery, GPS lock and
    recording state in a new status-bar cell.
    Protocol notes (lib/GoProManager):
    Speaks the GoPro Control & Query service (0xFEA6). Open GoPro documents
    this for HERO9+, but the subset used here is verified against a HERO8
    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
2026-08-03 Stop the 'model' partition shadowing the filesystem partition
    'pio run -t uploadfs' reported success while writing to the wrong flash
    region, and LittleFS.begin() then failed with error -1 against a blank
    partition. Neither side reported a mismatch.
    PlatformIO picks the filesystem partition by scanning for type=data with
    subtype spiffs/fat/littlefs and keeping the LAST match - fetch_fs_size()
    in the platform's builder/main.py assigns without a break. The table had
    two such partitions:
    spiffs, data, spiffs, 0x610000, 0x700000 <- LittleFS.begin() mounts this
    model, data, spiffs, 0xD10000, 0x2E0000 <- uploadfs wrote here
    'model' is reserved space for a future offline voice model (li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
    [JC3248W535N.csv]
2026-08-03 Shrink the LVGL draw buffers to free internal DRAM
    Two 40-line buffers held 76.8 kB of INTERNAL RAM - the same scarce pool
    WiFi must allocate from and cannot take from PSRAM. esp_wifi_init was
    failing with ESP_ERR_NO_MEM as a result.
    Cheap to reduce in this backend: the flush callback only copies into the
    full-frame canvas and blits once, on the last fragment, so halving the
    buffers doubles the memcpy count but not the QSPI traffic. 16 lines costs
    ~30 kB and leaves room for the radio. Tunable via GFX_DRAW_LINES.
2026-08-03 LapManager: expose the pre-lap best, and make gate tracing suppressible
    getPreviousBestLapTime() returns the best lap as it stood *before* the lap
    just completed. That is what a delta should be measured against: against
    getBestLapTime() it reads 0.00 on every personal best, because the best has
    already been updated to the lap being compared. Against the previous lap it
    only says whether you beat one sample. Callers move over in a later commit.
    setVerbose(false) silences the per-sample gate tracing. It emits two or
    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
2026-08-03 GoPro: hand the radio over on demand
    WiFi needs ~50 kB of internal DRAM and cannot take it from PSRAM; NimBLE
    is holding a comparable amount. On this board they cannot both be up, and
    esp_wifi_init fails with ESP_ERR_NO_MEM if BLE is still initialised.
    suspendRadio() disconnects, tears down and deinits the NimBLE stack;
    resumeRadio() brings it back. The worker also stands down while suspended,
    because deinit(true) destroys every client and its cached pointers with it.
    This is not a workaround so much as the real constraint: the camera and the
    WiFi portal are never wanted at the same time - one is racing, the other is
    sitting in the pits pulling files off the card.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
2026-08-03 Add the WiFi portal and on-device session review
    Two ways to look at a recorded session, because the enclosure is sealed and
    the SD card cannot be reached.
    lib/WebPortal — an on-demand SoftAP serving the card:
    GET / single-page app (embedded, no CDN: a browser on
    the AP has no route to the internet)
    GET /api/info card size + client count
    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
2026-08-03 Replace the sample log with a real recorded session
    real_car_ride.csv was in the old 6-column format the removed FakeGps
    expected, which nothing can read any more. kgv_20260801.csv is a real
    session off the device in the format LogManager writes, so it works with
    both the replay env and the on-device session browser.
    [kgv_20260801.csv, real_car_ride.csv]
2026-08-03 Add Barlow Condensed faces for the v2 dashboard numerals
    The v2 design's hero sizes (96/72/60/44 px) have no LVGL builtin. Generated
    with lv_font_conv from Google Fonts' BarlowCondensed-ExtraBold (SIL OFL),
    bpp 4, restricted to the glyphs a lap timer actually shows:
    0x2B '+' 0x2D '-' 0x2E '.' 0x30-0x39 digits 0x3A ':'
    That restriction is what makes 96 px affordable - the full Latin range would
    be an order of magnitude larger. Regeneration command is in DashFonts.h.
    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
2026-08-03 Store S1/S2 split gates per track
    A gate is two posts crossed between them, exactly like the finish line -
    which doubles as the third (END) gate. Purely additive: a tracks.ini with
    no sector keys parses as before and simply times whole laps, and the keys
    are only written when set, so such a track stays as terse as it was.
    0_s1_left_lat=... 0_s1_right_lat=...
    0_s2_left_lat=... 0_s2_right_lat=...
2026-08-03 Add sector timing to LapManager, and fix the gate proximity test
    Three gates instead of one: S1, S2 and the finish line. Sector n is closed
    by gate n and opened by the previous one, so S1/S2/S3 are END->S1, S1->S2
    and S2->END. Per-sector splits, bests, and a delta against the best that
    sector stood at *before* the current lap - the same rule the lap delta uses.
    A missed split can never corrupt a lap. Lap time comes from the finish line
    alone; if a split gate is missed only the affected sectors are voided. That
    is not hypothetical - a real 16-lap log has one.
    Also fixes a latent bug in the existing finish-line detection. The
    intersection test was gated on distance to the gate's CENTRE, but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
2026-08-03 Replace the SquareLine dashboard with the v2 design
    Port of "Dash Final v2.html" from the Claude Design project, adopted into
    lib/DashV2. Speed drops to a 72 px corner readout, the vs-best lap delta
    becomes a full-width 96 px hero band, the G-meter is gone and a sector band
    takes the bottom fifth. Local deviations from upstream are marked LOCAL:.
    Swapped rather than edited. The replacement screen is built and loaded, then
    SquareLine's own ui_dashboardscreen_screen_destroy() deletes the old one -
    which NULLs all 17 of its widget globals as a side effect, so the setters
    that used to touch them bail safely. Every _ui_screen_change() reference to
    ui_dashboardscreen stays valid, so navigation ne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
    [main_display.cpp]
2026-08-03 Add SECTOR 1 / SECTOR 2 rows to the track setup screen
    Four more coordinate rows below START LINE, built at runtime onto the
    SquareLine screen so the generated file stays untouched. Styling is copied
    from ui_panellinel rather than approximated - same 32 px height, surface,
    rule border, radius, padding, amber L/R tags, LAT/LON formatting and
    "-- not set --" placeholder - so they are indistinguishable from the two
    above them. PIN captures the current fix and flips to RESET; tapping a
    coordinate types it on the same numeric keyboard the start line uses.
    Two fixes found while wiring it up:
    * ui_panelbody had to shrink from 254 to 206 px. SquareLine gave it y=66
    h=254, running to y=320 -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
2026-08-03 Show sectors in the session browser and the web portal
    Both lap tables gain S1/S2/S3 columns, shown only when the selected track
    has both split gates. The best lap greens its whole row; a best sector
    greens only that cell, so "my quickest S2" reads differently from "my
    quickest lap". A lap whose split gate was missed shows "--" for that sector
    with its lap time intact.
    The browser reads splits off the real LapManager as each lap closes, at the
    finish line - where sectors 0 and 1 still hold that lap's values, since they
    are not cleared until the next S1. It also needed setSectorGates() adding
    after setFinishLine(), which clears them; without it hasSectors() stays
    false and every lap reports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
2026-08-06 overlay: support GPS9/HEVC GoPro footage
    Newer cameras (HERO11+) emit GPS9 with per-sample timestamp/DOP/fix
    instead of GPS5 + a separate GPSU stamp, and encode HEVC (hvc1/hev1)
    instead of avc1; gpmf_to_csv.py and prepare.py now handle both.
    Corrupt-sample rejection in gpmf_to_csv.py now anchors only on sats>0
    samples, since chaining stale no-fix points together could mask an
    implausible jump as a plausible speed.
2026-08-11 Stop the dash booting dark for five minutes over USB
    Plug the board into a computer with no serial monitor open and the screen
    stays black for about five minutes before coming up on its own. Attaching a
    monitor makes it start instantly. It looked like a charger or power fault
    for a long time; it is neither.
    The Arduino core prints a few hundred lines of chip, memory, partition and
    GPIO information from printBeforeSetupInfo(), gated on
    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
2026-08-11 Add charge mode: park the dash so the charger feeds the cell
    A manual-only low-power screen, entered from the CHARGE MODE button on the
    config screen — never automatically, so bench work and debugging are
    unaffected. It stops the session, quiesces the GPS, drops the CPU to 80MHz
    and blanks the backlight after 15s, so more of the charger's current budget
    reaches the battery instead of the dashboard.
    The charge screen and its config-screen button are hand-built in
    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
2026-08-11 Fix the battery reading undercounting by a dozen points
    The dash read 77% on a cell a multimeter put at 4.046V. Two faults stacked.
    The divider ratio was fitted at 4.224/2.47 with USB plugged in, so the sense
    node was sitting on the charger rail rather than the cell — about 2% low.
    Refitted against a meter on battery alone, confirmed at 4.00V.
    The percentage was then a straight line from 3.2 to 4.2V, which is the wrong
    shape for Li-ion: the cell spends most of its usable charge between 3.7 and
    3.8V, so the middle of the discharge read several points low. Replaced with an
    open-circuit-voltage table in 10% steps, interpolated inside each band.
    Also resample the cell on backlight wake in c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
    [main_display.cpp]
2026-09-04 Show when each SD file was written on the portal file list
    /api/list only reported name and size, so telling two log_N.csv files apart
    meant downloading both. It now also carries the file's mtime, appended after
    size so anything reading the existing keys is unaffected.
    getLastWrite() is only meaningful once LogManager::syncClockFromTelemetry() has
    run: the ESP32 boots at epoch 0, so files the card received before the first GPS
    fix are stamped 1970. The page gates on 1609459200 — kMinValidGpsEpochMs in
    seconds — and renders those as an em dash rather than a date that never
    happened, with the exact UTC instant on hover.
    The name cell also grows to absorb the row's slack, because four fle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
2026-09-04 Find the board on USB when flashing instead of trusting the pinned port (#22)
    * Find the board on USB when flashing instead of trusting the pinned port
    platformio.ini pins upload_port to /dev/cu.usbmodem1101, which is one machine's
    enumeration — the same board comes up as /dev/cu.usbmodem101 elsewhere, and
    `pio run -t upload` then fails on a port that is not there. tools/flash.sh
    discovers the port by USB VID:PID out of `pio device list --json-output` and
    passes it with --upload-port, which overrides the pinned value. Matching on
    VID:PID rather than the port name keeps this working on Linux and avoids
    parsing ioreg; 303A is the S3's native USB, and CP210x/CH340/FTDI are accepted
    for devki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
2026-09-04 Move the u-blox path to UBX-NAV-PVT at 25Hz, and make the log keep up
    Groundwork for a Matek M9N-5883 (NEO-M9N) that has not arrived yet. NOT TESTED ON
    HARDWARE. The log-path changes ship on the ATGM336 build in the meantime, so those
    need a flash and a real session before this is trusted.
    The u-blox provider now speaks UBX binary instead of NMEA. One NAV-PVT frame per
    epoch carries position at 1e-7 degrees (~1.1cm), Doppler ground speed, UTC, numSV,
    fixType, pDOP, hAcc and sAcc — less traffic than GGA+RMC (~100 bytes against ~145)
    and strictly more information, as one coherent snapshot rather than a position from
    one sentence stitched to a speed from another. It also disposes of the
    four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
    [main_display.cpp]
2026-09-04 Show the firmware version on the setup screen
    Right-aligned in the setup header, muted grey, from `git describe --tags --always
    --dirty` injected as FW_VERSION by a `!` command in build_flags. No version file to
    drift out of step:
    exact tag v1.2.0
    past a tag v1.2.0-4-gbf39cf3
    no tags yet bf39cf3
    uncommitted <any of the above>-dirty
    The -dirty suffix is as much the point as the version. This tree gets flashed
    directly, so uncommitted work is routinely what is actually running, and until now
    nothing on the dash could tell you that — it has already led to at least one wrong
    conclusion about whether a feature had been flashed at all.
    Placement was forced rathe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
2026-09-04 Log every NAV-PVT frame instead of one per UI pass
    The 25Hz session log was recording at 18.9Hz, losing 24% of its rows, and
    the health counter reported zero drops throughout.
    The loss was upstream of the queue. update() drained the whole UART buffer
    per call but this object holds a single fix, and main_display latched one
    bool that syncUI() consumed once per UI pass. Whenever loop() ran slower
    than 40ms every frame but the newest was overwritten before it could be
    enqueued, so the measured rate was really the loop rate.
    noteDroppedFrame() only counts xQueueSend failures, so none of it showed.
    update() now returns on each completed frame and leaves the rest buffered;
    loop() drains it with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
    [main_display.cpp]
2026-09-04 Capture the log on the device and show it on a screen
    The dash runs sealed with nothing on USB, and LOG_ERROR on this build is
    serial-only, so a failure at the track left just "GPS 0" on the display
    and no account of what happened. A session lost to that is what prompted
    this.
    LogBuffer taps the log at the ROM putc1 slot rather than wrapping
    LOG_ERROR, which catches every call site in the binary — ours, the
    Arduino core, LVGL, NimBLE — with no edits to any of them. Note that
    ARDUHAL does NOT route through esp_log_write unless USE_ESP_IDF_LOG is
    defined, so esp_log_set_vprintf alone sees almost nothing; that hook is
    kept as well, for the IDF components that do use it. Defining
    USE_ESP_ID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
    [main_display.cpp]
